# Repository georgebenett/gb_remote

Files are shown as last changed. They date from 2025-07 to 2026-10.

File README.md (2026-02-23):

# GB Remote

<div align="center">
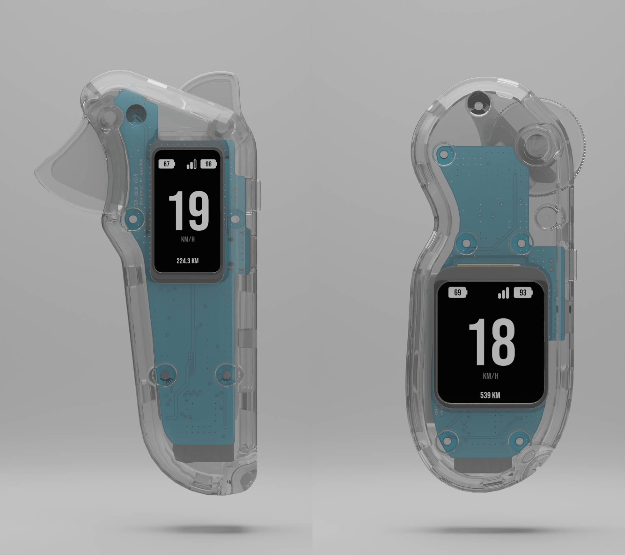
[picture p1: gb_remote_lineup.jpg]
GB Controller
  
</div>

A firmware open-source hand controller for electric skateboards built with the ESP32S3. This project provides a complete wireless control solution with real-time telemetry monitoring, featuring a custom BLE protocol that communicates with VESC motor controllers and Jiabaida/Kaly BMS systems.

This repository contains the **remote controller firmware**. The complete system also includes:
- **Receiver Firmware** (`gb_receiver`): The BLE server firmware that runs on the receiver

## Key Features

### Intuitive Control Interface
- **Analog Throttle Control**: High-precision ADC-based throttle input with automatic calibration
- **Dual Throttle Support**: Separate throttle and brake inputs on dual throttle variant with neutral position
- **Smart Button Interface**: Multi-function button with long-press and double-press detection
- **Haptic Feedback**: Vibration patterns for connection status, alerts, and user feedback
- **Sleep Management**: Automatic power management with inactivity detection and power modes
- **Power Management**: Soft latching hardware where power consumption while "sleeping is 1uA"

### Modern UI
- **LVGL Graphics Library**: Beautiful, responsive user interface built with EEZ Studio (open-source)
- **Real-time Speed Display**: Large, easy-to-read speedometer with km/h and mi/h display
- **Dual Battery Monitoring**: Separate battery indicators for controller and skateboard
- **Connection Status**: Visual feedback for BLE connection quality
- **Trip Distance Tracking**: Built-in odometer with persistent storage
- **Adjustable Backlight**: Configurable display brightness (1-100%)

### Comprehensive Telemetry
- **VESC Integration**: Real-time data from VESC
- **BMS Support**: Full battery management system monitoring with cell-level voltage tracking
  - **Compatible BMS Systems**: Jiabaida and Kaly BMS telemetry support
  - **Cell Voltage Monitoring**: Individual cell voltage tracking for up to 16 cells
  - **Capacity Tracking**: Real-time remaining and nominal capacity monitoring
- **Custom BLE Protocol**: Optimized data transmission for low latency and high reliability
- **Automatic Parameter Configuration**: Motor pulley, wheel diameter, and throttle settings are automatically retrieved by the receiver from the vesc

## Hardware Variants

The firmware supports two hardware variants:

### GB Remote Lite
- **Display**: 240×320 pixel TFT LCD
- **Throttle**: Single analog throttle with inversion support
- **Use Case**: Standard single-throttle control

### GB Remote Dual Throttle
- **Display**: 172×320 pixel TFT LCD
- **Throttle**: Dual analog inputs (throttle + brake)
- **Use Case**: Separate throttle and brake control with neutral position

Both variants share the same core firmware with target-specific configurations.

## Technical Specifications

### Hardware Platform
- **MCU**: ESP32 S3
- **Display**: TFT LCD ST7789 (resolution varies by variant)
- **Input**: Analog throttle with ADC calibration (dual inputs on dual throttle variant)
- **Connectivity**: Bluetooth Low Energy (BLE) SPP client
- **Power**: Built-in battery monitoring and power management
- **Haptic Feedback**: Vibration motor for user notifications

### Software Architecture
- **RTOS**: FreeRTOS for real-time task management
- **Graphics**: LVGL 8.3.6 with EEZ Studio UI
- **Communication**: Custom BLE SPP protocol for VESC/BMS data
- **Storage**: NVS flash for configuration and trip data
- **Power Management**: Advanced power modes and soft latching circuit

## Communication Protocol

### BLE SPP Protocol
- **Service UUID**: `0xABF0`
- **Data Characteristic**: `0xABF2`
- **Protocol**: Custom BLE SPP for low-latency communication with receiver
- **Data Exchange**: Throttle/brake commands from remote, VESC and BMS telemetry from receiver

### USB Serial Binary Protocol
The remote communicates with the configuration tool via a binary protocol over USB Serial (USB CDC):

- **Packet-based**: Binary protocol with CRC-16-CCITT error checking
- **Real-time Streaming**: Configurable data streaming (1-100 Hz) for monitoring and debugging
- **Commands**: Firmware version, configuration management, calibration, odometer control, BLE trim adjustment
- **Documentation**: See [`firmware/docs/USB_SERIAL_PROTOCOL.md`](firmware/docs/USB_SERIAL_PROTOCOL.md) for complete protocol specification

## Project Structure

This repository contains the **remote controller firmware**. The complete GB Remote system consists of:

1. **Remote Controller** (this repository): ESP32S3-based hand controller with display and throttle
2. **Receiver Firmware** (`gb_receiver`): BLE server firmware for the skateboard/receiver side that interfaces with VESC and BMS

## Getting Started

### Prerequisites
- ESP-IDF development environment

### Build & Flash

The project includes build scripts for easy compilation:

- **Lite variant**: `./lite_build.sh` - Builds for 240×320 display with single throttle
- **Dual Throttle variant**: `./dual_throttle_build.sh` - Builds for 172×320 display with dual throttle/brake
- **Release build**: `./build_and_release.sh` - Builds both variants for release

After building, flash using ESP-IDF:
```bash
idf.py flash monitor
```

Or use the [Configuration Tool](https://gbengineering.se/config-tool/) for easy firmware updates.

## Configuration Tool

**Easy Configuration via Web Interface**

Configure your GB Remote controller easily using our online configuration tool hosted on the GB Engineering website:

**[GB Remote Configuration Tool](https://gbengineering.se/config-tool/)**

The configuration tool provides a comprehensive web-based interface for setting up and managing your GB Remote system.

### Features:
- **USB Serial Connection**: Connect directly via USB cable
- **Real-time Configuration**: Adjust settings without recompiling firmware
- **Automatic Firmware Updates**: The configuration tool automatically checks for firmware updates every time the remote is connected. Update with a simple button confirmation
- **Throttle Calibration**: Calibrate throttle and brake inputs with guided calibration process
- **Speed Unit Toggle**: Switch between km/h and mph display units
- **Backlight Control**: Adjustable display brightness (0-100%)
- **BLE Trim Adjustment**: Fine-tune BLE output offset for precise throttle control
- **Odometer Management**: Reset trip distance counter
- **Real-time Data Streaming**: Monitor live telemetry data at configurable rates (1-100 Hz)
- **Status Monitoring**: Real-time device status and logs

### Quick Setup:
1. Flash the firmware to your Remote (and Receiver if needed)
2. Connect your controller via USB cable
3. Open the [Configuration Tool](https://gbengineering.se/config-tool/)
4. Click "Connect to Remote" to establish USB serial connection
5. Configure your settings and calibrate throttle

## BMS Compatibility

This controller is specifically designed to work with popular electric skateboard BMS systems:

- **Jaiabaida BMS**: Full telemetry support including cell voltages and capacity data
- **Kaly BMS**: Complete compatibility with all monitoring features

The receiver firmware (`gb_receiver`) handles the BMS communication and forwards the telemetry data to the remote controller via BLE.

## Contributing

This project is open source and welcomes contributions! Whether you're fixing bugs, adding features, or improving documentation, your help is appreciated.

### Pre-commit hooks

To enable auto-formatting (trailing whitespace trim + clang-format on C/C++ files) before each commit:

```bash
git config core.hooksPath githooks
```

Requires [clang-format](https://clang.llvm.org/docs/ClangFormat.html) (e.g. `brew install clang-format` on macOS).

## License

**Creative Commons Attribution-NonCommercial 4.0 International (CC BY-NC 4.0)**

This work is licensed under the Creative Commons Attribution-NonCommercial 4.0 International License. To view a copy of this license, visit [http://creativecommons.org/licenses/by-nc-nd/4.0/](http://creativecommons.org/licenses/by-nc-nd/4.0/).

### What this means:

**You are free to:**
- Share - copy and redistribute the material in any medium or format
- Adapt - remix, transform, and build upon the material
- Use for personal, educational, and research purposes

**You may NOT:**
- Use for commercial purposes (selling, commercial distribution, etc.)
- Create derivative works (modify and redistribute)
- Use without proper attribution to the original author

### Commercial Use:
For commercial use, licensing, or commercial distribution of this project, please contact the author for licensing terms and fees.

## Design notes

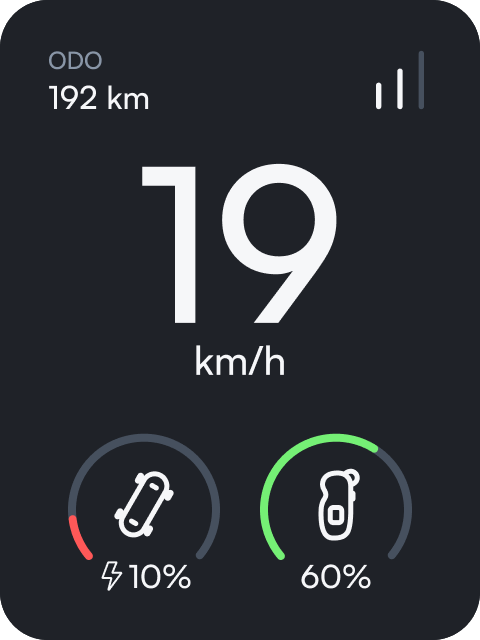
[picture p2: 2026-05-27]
UI/eez_dual_throttle/assets/reference.png

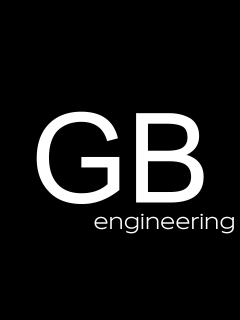
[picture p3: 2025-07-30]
UI/eez_dual_throttle/assets/GB.png

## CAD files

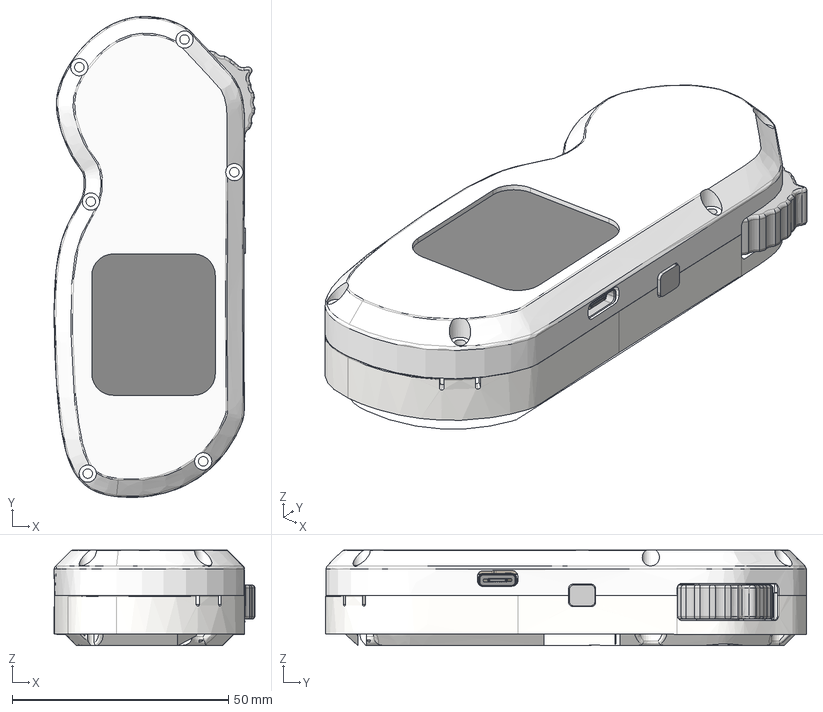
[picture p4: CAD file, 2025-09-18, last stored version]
mechanics/vesc hand controller prot 2 v31.step
46.5 x 111.3 x 24.0 mm
front cover
back cover
PCB (1)
Display (1)
R-0603 (1) x 3
C-0603 (1) x 2
U-0603 (1)
display cover
BOSS-EXTRUDE14_8_
BOSS-EXTRUDE7_4_
BOSS-EXTRUDE7_3_
BOSS-EXTRUDE14_4_
BOSS-EXTRUDE14_2_
BOSS-EXTRUDE14_11_
BOSS-EXTRUDE7_7_
BOSS-EXTRUDE14_9_
BOSS-EXTRUDE14_3_
BOSS-EXTRUDE14_7_
MIRROR2
BOSS-EXTRUDE14_5_
BOSS-EXTRUDE14_12_
BOSS-EXTRUDE7_8_
BOSS-EXTRUDE7_1_
BOSS-EXTRUDE14_10_
BOSS-EXTRUDE7_9_
BOSS-EXTRUDE14_6_
BOSS-EXTRUDE14_1_
BOSS-EXTRUDE7_6_
BOSS-EXTRUDE7_2_
CUT-EXTRUDE5
BOSS-EXTRUDE7_5_
U.FL Connector v1
Button (1) x 2
Shield
retreat v1
7487N25_Precision Stainless Steel Ball Bearing (1) x 2
new throttle
power switch
power button

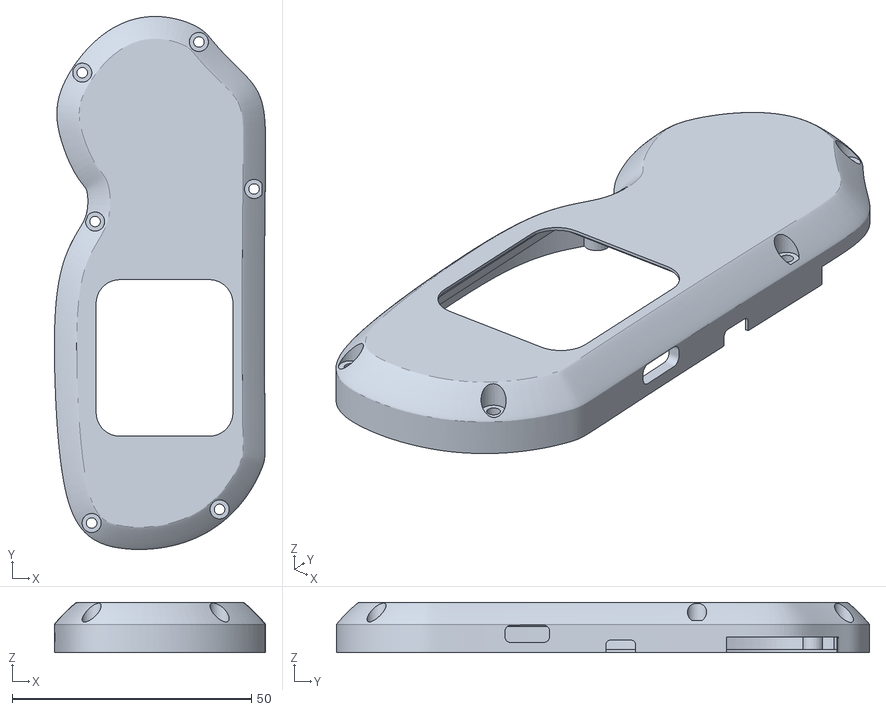
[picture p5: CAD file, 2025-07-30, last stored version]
mechanics/front.stl
44.1 x 111.3 x 10.5

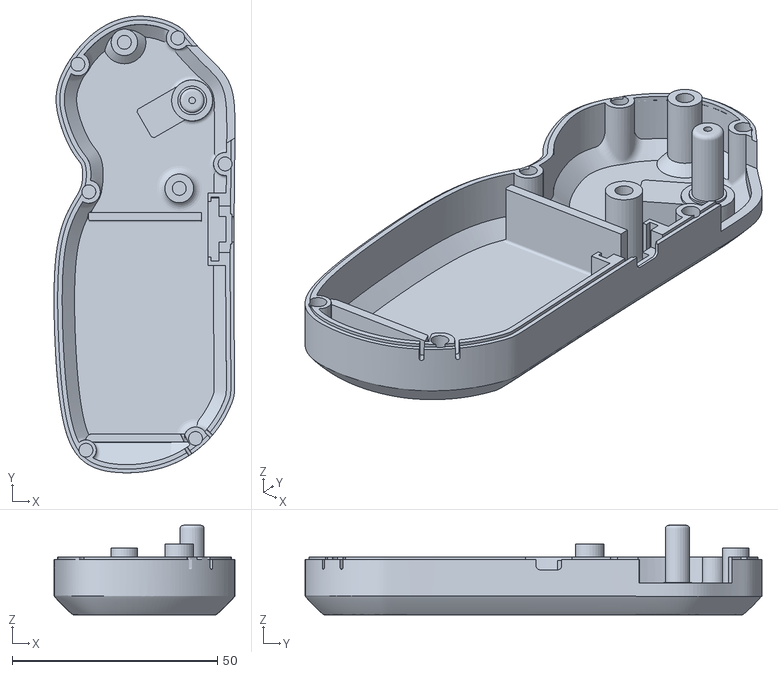
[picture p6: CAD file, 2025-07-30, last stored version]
mechanics/back.stl
44.1 x 111.3 x 21.8

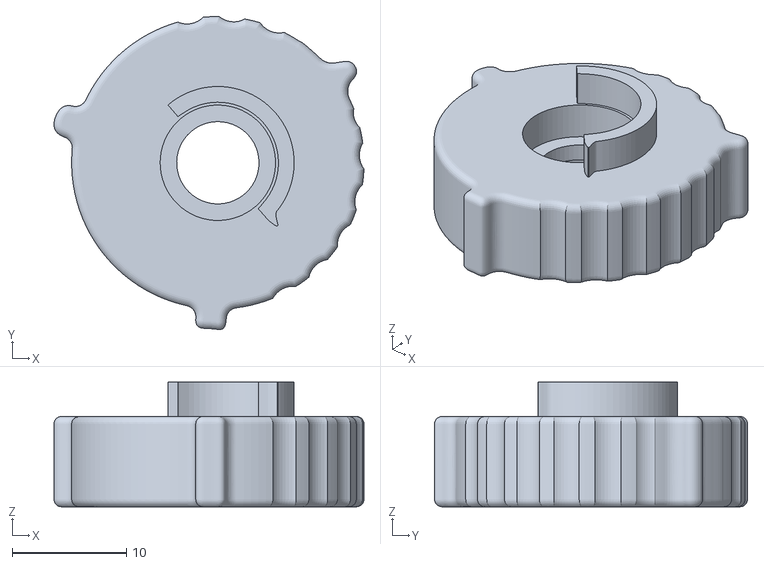
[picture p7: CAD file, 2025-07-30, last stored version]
mechanics/throttle.stl
27.1 x 27.4 x 10.9

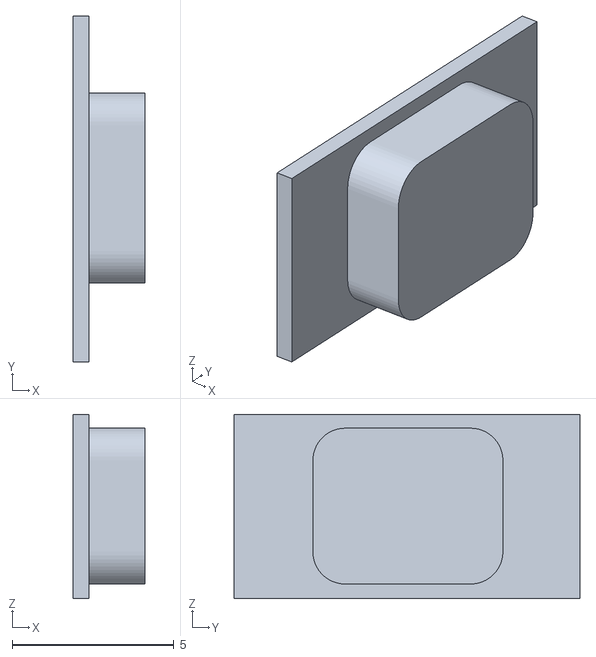
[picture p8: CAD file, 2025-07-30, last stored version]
mechanics/power_button.stl
2.23 x 10.7 x 5.70

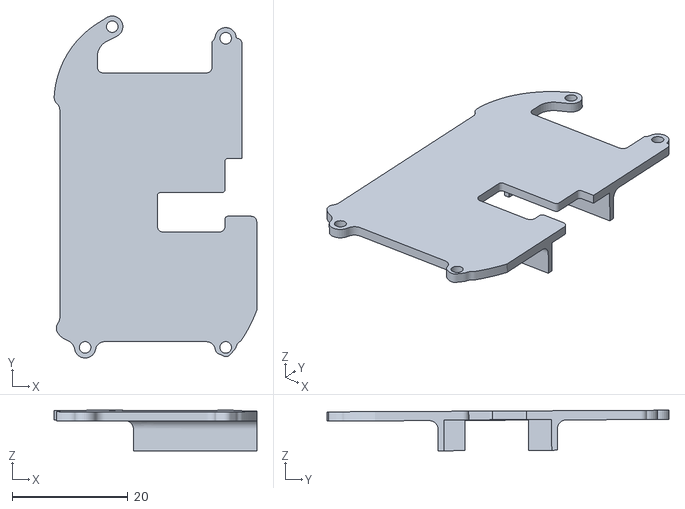
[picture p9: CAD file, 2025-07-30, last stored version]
mechanics/display_cover.stl
35.0 x 59.1 x 7.02

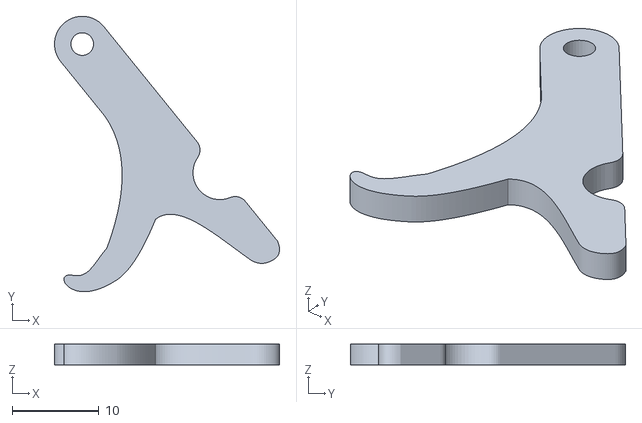
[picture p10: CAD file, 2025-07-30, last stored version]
mechanics/retreat.stl
25.9 x 31.7 x 2.40

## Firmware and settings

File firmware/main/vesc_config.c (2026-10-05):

#include "vesc_config.h"
#include "ble.h"
#include "esp_log.h"
#include "nvs.h"
#include "nvs_flash.h"
#include <math.h>

#define TAG "VESC_CONFIG"

// Current motor config from VESC (volatile, updated via BLE)
static vesc_motor_config_t current_motor_config = {
    .motor_poles = 10,        // Default until VESC sends config
    .gear_ratio_x1000 = 1000, // Default until VESC sends config
    .wheel_diameter_mm = 100, // Default until VESC sends config
};

// Default user preferences (saved to NVS)
static const vesc_config_t default_config = {
    .motor_poles = 11,        // Will be overwritten by VESC
    .gear_ratio_x1000 = 1001, // Will be overwritten by VESC
    .wheel_diameter_mm = 101, // Will be overwritten by VESC
    .speed_unit_mph = false,  // Speed unit: km/h by default
    .dual_connection = false, // Single receiver connection by default
    .battery_cells = 0,     // Unset: show pack voltage until user sets S count
    .battery_cell_type = 0, // High-drain li-ion (P42A/30Q/40T class)
    .smart_reverse = false,
    .no_reverse = false,
    .throttle_curve_acc = 0,
    .throttle_curve_brake = 0,
    .throttle_curve_mode = THROTTLE_CURVE_EXPO,
    .assist_push = false,
    .assist_strength = ASSIST_STRENGTH_DEFAULT,
    .assist_decay = ASSIST_DECAY_DEFAULT,
    .speed_limit_mode = 0,
    .ride_profile = RIDE_PROFILE_ROCKET,
#ifdef CONFIG_TARGET_LITE
    .invert_throttle = false // Throttle inversion disabled by default
#endif
};

esp_err_t vesc_config_init(void) {
  // Try to load user preferences, if it fails (first time) save defaults
  vesc_config_t config;
  esp_err_t err = vesc_config_load(&config);

  if (err == ESP_ERR_NVS_NOT_FOUND) {
    ESP_LOGI(TAG, "No user preferences found, saving defaults");
    return vesc_config_save(&default_config);
  }

  return err;
}

esp_err_t vesc_config_load(vesc_config_t *config) {
  nvs_handle_t nvs_handle;
  esp_err_t err;

  // Start with current motor config from VESC (or defaults if not yet received)
  config->motor_poles = current_motor_config.motor_poles;
  config->gear_ratio_x1000 = current_motor_config.gear_ratio_x1000;
  config->wheel_diameter_mm = current_motor_config.wheel_diameter_mm;

  config->speed_unit_mph = false;
  config->dual_connection = false;
  config->battery_cells = 0;
  config->battery_cell_type = 0;
  config->smart_reverse = false;
  config->no_reverse = false;
  config->throttle_curve_acc = 0;
  config->throttle_curve_brake = 0;
  config->throttle_curve_mode = THROTTLE_CURVE_EXPO;
  config->assist_push = false;
  config->assist_strength = ASSIST_STRENGTH_DEFAULT;
  config->assist_decay = ASSIST_DECAY_DEFAULT;
  config->speed_limit_mode = 0;
  config->ride_profile = RIDE_PROFILE_ROCKET;
#ifdef CONFIG_TARGET_LITE
  config->invert_throttle = false;
#endif

  err = nvs_open(VESC_NVS_NAMESPACE, NVS_READONLY, &nvs_handle);
  if (err != ESP_OK) {
    // No NVS data, use defaults - this is OK
    return (err == ESP_ERR_NVS_NOT_FOUND) ? ESP_OK : err;
  }

  uint8_t speed_unit;
  err = nvs_get_u8(nvs_handle, NVS_KEY_SPEED_UNIT, &speed_unit);
  if (err == ESP_OK) {
    config->speed_unit_mph = (bool)speed_unit;
  }

  uint8_t dual_connection;
  err = nvs_get_u8(nvs_handle, NVS_KEY_DUAL_CONNECTION, &dual_connection);
  if (err == ESP_OK) {
    config->dual_connection = (bool)dual_connection;
  }

  uint8_t battery_cells;
  err = nvs_get_u8(nvs_handle, NVS_KEY_BATTERY_CELLS, &battery_cells);
  if (err == ESP_OK) {
    config->battery_cells = battery_cells;
  }

  uint8_t battery_cell_type;
  err = nvs_get_u8(nvs_handle, NVS_KEY_BATTERY_CELL_TYPE, &battery_cell_type);
  if (err == ESP_OK) {
    config->battery_cell_type = battery_cell_type;
  }

  uint8_t smart_reverse;
  err = nvs_get_u8(nvs_handle, NVS_KEY_SMART_REVERSE, &smart_reverse);
  if (err == ESP_OK) {
    config->smart_reverse = (bool)smart_reverse;
  }

  uint8_t no_reverse;
  err = nvs_get_u8(nvs_handle, NVS_KEY_NO_REVERSE, &no_reverse);
  if (err == ESP_OK) {
    config->no_reverse = (bool)no_reverse;
  }

  /* Out-of-range curve values are dropped, not clamped: a bad read gives the
   * rider linear, not a shape they never asked for. */
  int8_t curve_acc;
  err = nvs_get_i8(nvs_handle, NVS_KEY_CURVE_ACC, &curve_acc);
  if (err == ESP_OK && curve_acc >= THROTTLE_CURVE_MIN &&
      curve_acc <= THROTTLE_CURVE_MAX) {
    config->throttle_curve_acc = curve_acc;
  }

  int8_t curve_brake;
  err = nvs_get_i8(nvs_handle, NVS_KEY_CURVE_BRAKE, &curve_brake);
  if (err == ESP_OK && curve_brake >= THROTTLE_CURVE_MIN &&
      curve_brake <= THROTTLE_CURVE_MAX) {
    config->throttle_curve_brake = curve_brake;
  }

  uint8_t curve_mode;
  err = nvs_get_u8(nvs_handle, NVS_KEY_CURVE_MODE, &curve_mode);
  if (err == ESP_OK && curve_mode < THROTTLE_CURVE_MODE_COUNT) {
    config->throttle_curve_mode = curve_mode;
  }

  uint8_t assist_push;
  err = nvs_get_u8(nvs_handle, NVS_KEY_ASSIST_PUSH, &assist_push);
  if (err == ESP_OK) {
    config->assist_push = (bool)assist_push;
  }
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

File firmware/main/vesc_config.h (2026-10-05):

#ifndef VESC_CONFIG_H
#define VESC_CONFIG_H

#include "esp_err.h"
#include "sdkconfig.h"
#include "throttle_math.h"
#include <stdbool.h>
#include <stdint.h>

// NVS Storage keys (only user preferences are persisted)
#define VESC_NVS_NAMESPACE "vesc_cfg"
#define NVS_KEY_SPEED_UNIT "speed_unit"
#define NVS_KEY_DUAL_CONNECTION "dual_conn"
#define NVS_KEY_BATTERY_CELLS "batt_cells"
#define NVS_KEY_BATTERY_CELL_TYPE "batt_celltyp"
#define NVS_KEY_SMART_REVERSE "smart_rev"
#define NVS_KEY_ASSIST_PUSH "assist_push"
#define NVS_KEY_ASSIST_STRENGTH "assist_str"
#define NVS_KEY_ASSIST_DECAY "assist_dec"
#define NVS_KEY_NO_REVERSE "no_reverse"
#define NVS_KEY_CURVE_ACC "curve_acc"
#define NVS_KEY_CURVE_BRAKE "curve_brk"
#define NVS_KEY_CURVE_MODE "curve_mode"
#define NVS_KEY_SPEED_LIMIT "speed_limit"
#define NVS_KEY_RIDE_PROFILE "ride_profile"

// Speed limit modes: Off, 20 km/h, 25 km/h, 20 mph, 25 mph.
#define SPEED_LIMIT_MODE_COUNT 5

// Ride profiles: Beginner, Eco, Medium, Rocket.
#define RIDE_PROFILE_COUNT 4
#define RIDE_PROFILE_ROCKET (RIDE_PROFILE_COUNT - 1) // instant, no cap

// Assistive push tuning, clamped again by the receiver that runs it.
#define ASSIST_STRENGTH_DEFAULT 15 // percent of the VESC current limit
#define ASSIST_STRENGTH_MIN 5
#define ASSIST_STRENGTH_MAX 50
#define ASSIST_DECAY_DEFAULT 30 // motor rpm/s bled off the held speed
#define ASSIST_DECAY_MIN 10
#define ASSIST_DECAY_MAX 120
#ifdef CONFIG_TARGET_LITE
#define NVS_KEY_INVERT_THROTTLE "inv_throttle"
#endif

// Motor configuration from VESC (received via BLE, NOT persisted)
typedef struct {
  uint8_t motor_poles;        // Number of motor poles (from VESC via BLE)
  uint16_t gear_ratio_x1000;  // Gear ratio * 1000 (from VESC via BLE)
  uint16_t wheel_diameter_mm; // Wheel diameter in mm (from VESC via BLE)
} vesc_motor_config_t;

// Full config including user preferences
typedef struct {
  // Motor config from VESC (volatile - not saved to NVS)
  uint8_t motor_poles;        // Number of motor poles (from VESC via BLE)
  uint16_t gear_ratio_x1000;  // Gear ratio * 1000 (from VESC via BLE)
  uint16_t wheel_diameter_mm; // Wheel diameter in mm (from VESC via BLE)
  // User preferences (persisted to NVS)
  bool speed_unit_mph;       // Speed unit: false = km/h, true = mph
  bool dual_connection;      // Allow connecting to two receivers simultaneously
  uint8_t battery_cells;     // Skate pack series count: 0 = unset (show pack
                             // voltage), else 5..20 (estimate percentage)
  uint8_t battery_cell_type; // Cell chemistry (battery_cell_type_t) picking
                             // which SoC curve the estimate uses
  bool smart_reverse;        // VESC-style smart reverse, run by the receiver
  bool no_reverse;           // Below neutral only brakes, run by the receiver
  int8_t throttle_curve_acc; // Throttle curve, tenths (see throttle_math.h)
  int8_t throttle_curve_brake; // Brake curve, tenths
  uint8_t throttle_curve_mode; // throttle_curve_mode_t
  bool assist_push;        // Assistive push (endless mode), run by the receiver
  uint8_t assist_strength; // Assistive push strength, percent of current limit
  uint8_t assist_decay;    // Assistive push decay, motor rpm/s
  uint8_t speed_limit_mode; // 0 off, 1 20km/h, 2 25km/h, 3 20mph, 4 25mph;
                            // enforced by the receiver
  uint8_t ride_profile;     // 0 Beginner .. 3 Rocket: eased throttle ramp here,
                            // drive current cap on the receiver. Rocket = off.
#ifdef CONFIG_TARGET_LITE
  bool invert_throttle; // Whether to invert throttle direction
#endif
} vesc_config_t;

esp_err_t vesc_config_init(void);
esp_err_t vesc_config_load(vesc_config_t *config);
esp_err_t
vesc_config_save(const vesc_config_t *config); // Only saves user preferences
int32_t vesc_config_get_speed(const vesc_config_t *config);

// The cap a speed_limit_mode enforces, in km/h; 0 means no limit.
float vesc_config_speed_limit_kmh(uint8_t speed_limit_mode);

// Time (ms) a profile takes to ramp neutral -> full throttle; 0 = instant.
// Braking is never ramped.
uint16_t vesc_config_ride_profile_ramp_ms(uint8_t ride_profile);

// Percent of max motor current the profile may drive; enforced by the receiver.
uint8_t vesc_config_ride_profile_current_pct(uint8_t ride_profile);

// Update motor config from VESC (called by BLE when data is received)
void vesc_config_update_motor(uint8_t motor_poles, uint16_t gear_ratio_x1000,
                              uint16_t wheel_diameter_mm);

#endif // VESC_CONFIG_H

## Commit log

2025-07-30 adding mech
    [back.stl, display_cover.stl, front.stl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]
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2025-08-26 fixing partition size to fit coredump on flash
    [partitions.csv]
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2025-09-18 adding remote step file
    [vesc hand controller prot 2 v31.step]
2025-09-19 fixing mi/h and km/h text on UI at boot
    [vesc_config.c]
2025-09-19 fixing battery level calibration
    [battery.c, battery.h]
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2025-10-16 porting to EEZ Studio
    [partitions.csv]
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2025-10-31 fixing adc wrongly naming, replace with throttle name instead
    [battery.c, battery.h, lcd.c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]
2025-10-31 fix generic function naming from adc to throttle
    [throttle.c, throttle.h]
2025-11-01 inverting screen 180 degrees
    [lcd.c]
2025-11-01 removing invert throttle
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2025-11-02 adding power module, adding vesc voltage display if bms is not connected
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2025-11-02 fix stack overflow on button task
    [button.c]
2025-11-03 fixing backlight levels and flash script
    [lcd.c, lcd.h, power.c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]
2025-11-03 ui_updater: fix unused function
    [ui_updater.c, ui_updater.h]
2025-11-04 fix buildtree
    [back.stl, display_cover.stl, front.stl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]
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2025-11-11 fix timing on the ui tasks to have more stability
    [lcd.c, throttle.c, ui_updater.c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]
2025-11-12 fix ui functions not taking mutex first
    [ui_updater.c]
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2025-11-12 rework on power module
    [ble.c, button.c, power.c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]
2025-11-18 viber: higher short pulsing time
    [viber.c]
2025-12-01 fix dual throttle calibration handling
2025-12-01 ui_updater: write to nvs when reset odometer
    [ui_updater.c]
2025-12-01 fix invert throttle
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2025-12-11 replace direct mutex calls with command queue for all LVGL updates
    [power.c, ui_updater.c]
2025-12-11 fix calibration bug on dual throttle
    [ble.c, throttle.c, throttle.h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]
2025-12-11 rework on serial handler, motor config aquired from server at runtime
    [ble.c, vesc_config.c, vesc_config.h]
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2025-12-13 dual throttle raw adc inverted logic
    [throttle.c]
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2025-12-14 fix battery init in throttle
    [battery.c, battery.h, throttle.c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]
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2025-12-17 ble: fix type-limits warning
    [ble.c]
2025-12-17 Add wake-up from sleep with long press on main button
    - Configure button GPIO as wake-up source before entering deep sleep
    - Add power_check_wake_from_sleep() to detect wake and verify long press
    - Require 500ms long press to turn device on after sleep
    - Add power_sleep_immediate() for quick sleep when wake-up check fails
    - Check wake-up status early in app_main() before full initialization
    [power.c]
2026-01-06 Fix: Invert trim offset when throttle is inverted
    When throttle inversion is enabled, the trim offset direction must also be inverted to maintain correct compensation. This ensures that trim adjustments work correctly regardless of throttle inversion state.
    [ble.c]
2026-01-09 Optimize task timings and add LVGL mutex protection
    - Reduce task frequencies to improve system stability:
    * ADC task: 20ms -> 30ms (50Hz -> 33Hz)
    * LVGL handler: 10ms -> 16ms (100Hz -> 62.5Hz)
    * USB serial: 10ms -> 20ms (100Hz -> 50Hz)
    * Button monitor: 10ms -> 20ms (100Hz -> 50Hz)
    * Speed update: 20ms -> 50ms (50Hz -> 20Hz)
    * BLE ADC send: 50ms -> 75ms (20Hz -> ~13Hz)
    - Add mutex protection for all LVGL screen switching operations:
    * power.c: Screen switching now thread-safe
    * button.c: Screen switching now thread-safe
    * Fixes race condition causing delayed home screen return
    - Fix variable scope in usb_serial.c (throttle_inverted)
    - Bump version to 1.2.0
    [ble.c, button.c, lcd.c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]
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2026-01-23 Add BLE pairing and paired device persistence (v2.0.0)
    - Add NVS storage for paired server MAC address
    - Implement BLE security with passkey authentication (MITM protection)
    - Prioritize reconnecting to last paired device on startup/disconnect
    - Fall back to scanning for any device after 15 second timeout
    - Fix scan race condition by waiting for stop complete event before restarting
    - Remove unnecessary watchdog from connection update task
    [ble.c, ble.h, ui_updater.c]
2026-01-26 fix button handling to interrupt based instead of polling
    [button.c]
2026-02-03 fix button_monitor task watchdog timeout and reduce BLE reconnect timeout
    - Fix watchdog trigger by replacing portMAX_DELAY with 4s timeout in button task
    - Add watchdog reset in startup button-release wait loop
    - Reduce BLE paired device reconnect timeout from 15s to 5s
    [ble.c, button.c]
2026-02-05 refactor: clean up main.c structure and improve modularity
    - Move backlight loading/fading to lcd.c (lcd_load_saved_brightness, lcd_fade_to_saved_brightness)
    - Move splash screen logic to ui_updater.c (ui_show_splash_screen)
    - Encapsulate power wake check inside power_init() - no longer exposed in header
    - Use ble_is_connected() instead of extern is_connect
    - Make error handling consistent: ESP_ERROR_CHECK for critical only (button, adc, battery)
    - Non-critical failures (viber, vesc_config) now log warnings and continue
    - Remove duplicate ui_update_aux_output_indicator call
    - main.c reduced from 166 to 119 lines, now pure orchestration
    [lcd.c, lcd.h, power.c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]
2026-02-05 fix: resolve task watchdog timeouts in UI update tasks
    - Move watchdog reset to start of loop in all UI tasks
    - Split connection_update_task's 5s delay into 1s chunks
    - Ensures watchdog is reset before any potentially blocking operations
    The conn_update task was triggering watchdog because it slept for
    5 seconds (CONNECTION_UPDATE_MS) which equals the watchdog timeout.
    [ui_updater.c]
2026-02-05 refactor: improve code quality and industry standards compliance
    - Add named constants for magic number delays across all modules
    - Fix BREAK_PIN typo to BRAKE_PIN in hw_config.h and throttle.c
    - Replace extern variable with getter function (power_is_entering_off_mode)
    - Replace assert() with proper error handling in lcd.c buffer allocation
    - Remove dead code (unreachable vTaskDelete in ble.c)
    - Add comprehensive error handling documentation in main.c
    - Use volatile for shared state visibility across tasks
    - Remove watchdog from non-critical connection_update_task
    [battery.c, ble.c, lcd.c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]
2026-02-05 fix: improve BLE thread safety and ADC reliability
    - Replace direct is_connect access with thread-safe ble_is_connected()
    - Make is_connect static and remove extern declaration from header
    - Fix memory leak in MTU reconfig by freeing db before reallocation
    - Fix incorrect reconnect timeout log message (was hardcoded)
    - Improve throttle/brake ADC validation with min sample requirement
    - Add stuck-value detection for throttle/brake sensors
    - Add outlier rejection to battery ADC using trimmed mean
    [battery.c, ble.c, ble.h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]
2026-02-05 fix: critical safety and reliability improvements
    CRITICAL SAFETY FIXES:
    - Fix LITE mode ADC error handling: errors now map to neutral (128), not throttle (0)
    - Block throttle transmission when battery is critically low
    - Add division-by-zero protection in map_throttle_value() and map_brake_value()
    THREAD SAFETY FIXES:
    - Replace all direct is_connect access with ble_is_connected() for mutex protection
    - throttle.c, power.c, ui_updater.c, usb_serial.c, ble.c (adc_send_task)
    RELIABILITY IMPROVEMENTS:
    - Add neutral dead zone (±3 units) to prevent unintended motion from ADC noise
    - Add watchdog registration to connection_update_task
    - Validate calibration values on NVS load (range, min<max,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
    [ble.c, power.c, throttle.c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]
2026-02-15 swapped mi/h to mph
    [ui_updater.c, vesc_config.h]
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2026-03-01 fix race in adc_send_task
    [ble.c]
2026-03-01 fix ble watchdog bug
    [ble.c]
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2026-03-03 fix ble throttle issue!
    [ble.c, ble.h, power.c]
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2026-03-06 fix throttle center point in lite
    [throttle.c]
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2026-04-01 remove receiver-side reconnect preference logic
    Reconnect intelligence has moved to the receiver. Remote no longer saves
    or filters by receiver MAC — it simply scans for any GS-THUMB device on
    boot and after disconnect. Removes paired server NVS storage, reconnect
    timer, and reconnect handler task.
    [ble.c, ble.h]
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2026-04-09 fix adc calibration lock when empty flash
    [throttle.c]
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2026-04-23 fix lite power state ui icon location
2026-04-24 add throttle calibration error to UI
    [ui_updater.c, ui_updater.h]
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2026-04-25 Fix shutdown completion feedback and timing
    [power.c]
2026-04-26 add reset odometer function to remote: odometer is saved into receiver nvs, remote sends a command to resets its odometer
    [ble.c, ble.h]
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2026-04-27 use per-target build dirs and sdkconfig files to avoid mutating shared config on target switch
2026-05-06 add mutex to adc_oneshot to avoid race conditions
    [battery.c, throttle.c, throttle.h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]
2026-05-06 fix vesc voltage not showing when bms disconnected
    [ble.c, ui_updater.c]
2026-05-07 fix a few bugs on snake game
    [throttle.c]
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2026-05-13 harden build_and_release.sh against wrong-chip releases
    force idf.py set-target from sdkconfig.defaults.<target> at the start of
    each build, and assert bootloader byte 12 matches the expected chip id
    before packaging. v2.1.15 shipped a c3 bootloader because a stale
    sdkconfig overrode the s3 defaults; this catches that at release time
    instead of on the device side.
2026-05-13 advertise GS-REM while not connected for pairing discovery, v2.2.0
    The receiver scans for nearby remotes by their advertised name during
    the pair flow. Add non-connectable advertising (ADV_TYPE_NONCONN_IND)
    that runs whenever the remote is idle (not connected, not suspended)
    and is stopped on connect/suspend. GATT-client behavior is unchanged.
2026-05-16 reduce BLE throttle latency for racing
    - ADC_SEND_INTERVAL_MS 75 → 20 ms (50 Hz send rate)
    - ADC_SAMPLING_TICKS 30 → 15 ms (fresher cached value)
    - Request 20 ms BLE connection interval on connect so the stack
    delivers packets at the rate we send them
    - Dual throttle: use cached adc_get_latest_value() in send path instead
    of calling get_throttle_brake_ble_value() which did 10 fresh ADC reads
    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
2026-05-20 add neutral deadband macro, neutral window was too tight on remotes
    [ble.c, vesc_config.h]
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2026-05-28 add missing dual throttle files
2026-07-29 throttle: dedupe ADC reads and centralize trim mapping
    - Fold throttle_read_value/brake_read_value into one adc_read_avg helper;
    they were byte-identical apart from the channel and log string.
    - Add throttle_apply_trim(), the single implementation of the trim/neutral
    mapping that ble.c and usb_serial.c each had their own copy of.
    - Make map_throttle_value static and lite-only, dropping the map_adc_value
    wrapper that only forwarded to it.
    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
2026-07-29 battery: drop unused and duplicated constants
    BATTERY_MAX_VOLTAGE was never read, and ADC_SAMPLE_MS is already defined in
    throttle.h, which battery.c includes.
2026-07-29 ble: drop the single-profile dispatch table and unused telemetry state
    - Remove gl_profile_tab / gattc_profile_inst: with PROFILE_NUM == 1 the
    lookup loop always resolved to the one handler, so esp_gattc_cb now calls
    gattc_profile_event_handler directly and keeps the interface in
    spp_gattc_if (typed esp_gatt_if_t, ESP_GATT_IF_NONE until registered).
    - Delete spp_uart_init/uart_task and spp_uart_queue: nothing ever fed
    UART0 data to the receivers, and the driver install held 12 KB.
    - Stop caching temperatures, currents, cell voltages and cell count that
    no screen reads; they are decoded locally for the log line only.
    - Use throttle_apply_trim() instead of an inline copy of the trim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
    [ble.c, ble.h]
2026-07-29 ui_updater: remove dead API and share the splash label setup
    - Drop ui_create_aux_output_indicator(), a NULL check plus a call to
    ui_update_aux_output_indicator(); app_init now calls the latter directly.
    - Delete ui_update_connection_quality()/get_connection_quality() and the
    connection_quality state: ble.c calls ui_update_connection_icon() itself.
    - Delete ui_check_mutex_health() (never called; swapping a live mutex
    under waiters was unsound anyway) and take_lvgl_mutex_for_handler().
    - Factor the firmware version + MAC label fill into splash_set_labels(),
    duplicated between ui_show_splash_then_home and ui_show_splash_screen.
    - Drop the never-implemented motor/battery current and con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
    [ui_updater.c, ui_updater.h]
2026-07-29 button: remove unused state tracking and screen callback
    - Drop button_state_t and current_state: nothing read them, the events
    already carry the transition.
    - Delete button_get_state, button_get_press_duration_ms,
    button_unregister_callback, the no-op default handler and
    switch_to_screen2_callback (shutdown screen is driven from power.c).
    - Remove the second button_start_monitoring() call in app_init; it is
    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
2026-07-29 usb_serial: add LE payload writers and one charging-mode gate
    - Add put_u16/put_u32 helpers and use them for every little-endian field;
    the manual four-line shift-and-mask blocks appeared 20+ times.
    - Reject commands that need the full app once in
    usb_serial_process_packet() via cmd_needs_full_mode(), instead of the
    same POWER_MODE_CHARGING check repeated in nine handlers.
    - Use throttle_apply_trim() instead of the local copy of the trim mapping.
    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
2026-07-29 vesc_config: drop unused vesc_config_get_motor
    Nothing read the motor config back out; the values are consumed straight
    from vesc_config_t.
2026-07-29 viber: replace the pattern switch with a lookup table
    The seven-case switch only picked an array and its length. A table indexed
    by viber_pattern_t does the same with a bounds check.
    Also drop viber_vibrate, viber_custom_pattern, viber_stop and the shutdown
    song: no caller, and shutdown already has its own haptic feedback.
    [viber.c, viber.h]
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2026-08-30 add shutdown command to avoid failsafe when turning off the remote manually whule still connected to the board
    [ble.c, ble.h, power.c]
2026-09-15 add support for smart reverse and some bug fixing
    [ble.c, ble.h, throttle.c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]
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2026-10-05 add ride profiles, speed limit and shutdown arc (v3.0.4)
    Ride settings
    - New CMD_SET_RIDE_SETTINGS (profile + speed limit mode), persisted in NVS
    and applied live without a reboot.
    - Ride profiles (Beginner/Eco/Medium/Rocket): the remote eases the throttle
    up from neutral with an ease-in ramp (braking, release and neutral pass
    through instantly); the receiver caps drive current by profile.
    - Speed limit modes (off, 20/25 km/h, 20/25 mph) are enforced by the
    receiver. Both settings are sent over BLE on every (re)connect and on
    change via new commands 0x06 and 0x09.
    USB config
    - New CMD_GET_ALL / RSP_ALL: one tagged TLV snapshot of all settings,
    read from NVS, so the config tool n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
    [ble.c, ble.h, power.c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]
2026-10-05 port to lvgl 9.1.0 for esp32s3 SIMD, dual pro colors and home animations
    - LVGL 9.1.0 + esp_lvgl_port 2.4.4 for the S3 SIMD fill/blend routines;
    vendored components updated
    - lcd.c on the LVGL 9 display API: async DMA flush, RGB565 swap in flush,
    tick callback, LVGL task on core 1 sleeping until its next timer
    - perf defaults: -O2, 240 MHz, 64/32 KB caches, 80 MHz PSRAM, 1 kHz ticks,
    15 ms refresh; LVGL pool (128 KB) malloc'd into PSRAM, BT allocs PSRAM first
    - 3 MB app partition
    - images converted to LVGL 9 ARGB8888; fonts repacked to 4 bpp (LVGL 9.1
    renders 8 bpp glyphs scrambled); unused ui_image_reference.c removed
    - dual pro palette on home/charging/low battery screens, "odo km/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
    [partitions.csv]
2026-10-05 smooth arc fills: tenth-percent arc resolution
    Gauge arcs (charging, home remote/board) and the shutdown fill ran in whole
    percents, 2.6 degree jumps that the slow tail of the ease showed as steps.
    They now run 0-1000, LVGL's 1 degree limit, so fills glide to the end.
    Callers still pass percent to the gauges; the shutdown fill takes
    SHUTDOWN_PROGRESS_MAX (1000).
2026-10-24 raise assist strength cap to 80% (v3.0.5)
    Assistive push strength now goes up to 80% of the VESC current limit (was 50%).
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2026-10-30 githooks: quote the macOS sed suffix, skip partially staged files
    `sed -i ''` expanded unquoted left file'' backups behind on macOS (hence
    the *'' ignore rules, now gone). Re-adding a formatted file also staged
    its unstaged hunks; such files are skipped now. post-commit called a
    script that no longer exists.
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2026-10-30 usb_serial: block on driver reads, drop stalled frames
    The task read one byte through stdin and slept 20 ms after every byte,
    capping RX near 50 B/s (120-200 ms per command). Read up to 64 bytes per
    usb_serial_jtag_read_bytes() call with a 10 ms timeout and parse them all;
    a frame that stalls for 50 ms mid-way resets the parser.
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2026-10-30 settings: one RAM-cached store owns all NVS; atomic calibration
    vesc_config.c becomes settings.c and owns every persisted value (prefs,
    backlight, haptics, aux, trim, snake score, throttle calibration). It
    loads once at boot from the existing namespaces and keys, so nothing is
    migrated; getters copy from RAM, setters validate, write only changed
    keys and bump settings_epoch(). No other module calls nvs_*.
    - No NVS reads in steady state: the speed/battery tasks reloaded from
    flash every ~2.5 s and the USB stream on every tick.
    - An NVS error no longer aborts (ESP_ERROR_CHECK in a UI task, and
    nvs_flash_init at boot); the remote runs on defaults instead.
    - One defaults table (10 poles, 1: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
2026-10-30 viber: one preemptible request slot, callers never block
    A request is now xQueueOverwrite()n into a 1-slot queue; the task blocks
    on it and waits each step on the same queue, so a new pattern cuts the
    current one short instead of being dropped, and durations/count can no
    longer disagree mid-update. Callers (including an LVGL animation
    callback and the button task) no longer sleep 10 ms. The startup song
    goes through the same task, haptic steps restore their frequency after
    it, LEDC setup is shared, and init returns errors instead of aborting.
2026-10-30 concurrency: atomics for cross-task flags, check task creation
    - ble_is_connected() read the flag whether or not its 10 ms mutex take
    succeeded; it is an atomic now and the mutex is gone.
    - power_check_inactivity()/power_check_charging_screen_usb() looked at
    the active screen from the main loop without the LVGL mutex.
    - ui_set_dual_home_screen() rebound widgets unlocked after 5 failed
    takes; it waits now (callers are init and the USB task).
    - volatile flags shared between tasks are stdatomic.
    - Every xTaskCreate is checked and fails init loudly.
    - button: ISR service install/handler add are checked; the isr_triggered
    flag duplicated the task notification.
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2026-10-30 logging: per-event/per-packet at DEBUG, repeated warnings once a second
    The console shares the USB-Serial-JTAG port with the config tool's binary
    protocol. Every GATTC event, notify and write completion logged at INFO;
    those are DEBUG now (compiled out at the INFO default, made explicit in
    sdkconfig.defaults). The failed-throttle-write and ADC fault warnings,
    which can fire every 20 ms, are rate-limited to once a second.
2026-10-30 battery: eFuse-calibrated ADC voltage, no fudge factor
    The reading was raw / 4095 * 3.3 V * 2 * 1.075 with the calibration
    headers included but unused. It now goes through the curve-fitting
    calibration scheme (true millivolts); the 1.075 fudge only applies on a
    chip without calibration eFuses. BATTERY_VOLTAGE_SCALE stays as a trim
    knob for divider tolerance.
    Needs hardware check: compare against a multimeter across the range and
    re-check the 2.95 V cut-off (BATTERY_LOW_VOLTAGE_THRESHOLD).
2026-10-30 power: dynamic frequency scaling, 240 MHz only while LVGL renders
    CONFIG_PM_ENABLE + tickless idle, esp_pm_configure(240/80 MHz). Without a
    lock DFS would run LVGL at 80 MHz, so the LVGL task holds a CPU_FREQ_MAX
    lock around lv_timer_handler(); between frames the CPU drops to 80. SPI
    and BT drivers take their own APB locks. No automatic light sleep.
    Needs hardware check: battery current before/after, UI frame rate, BLE
    link stability. Existing build_<variant>/ trees keep their old sdkconfig;
    delete sdkconfig.<variant> to pick up the new defaults.
2026-10-30 ble: bonded receivers only, pairing window, encrypted-only sends
    - The passkey is CONFIG_GB_BLE_PASSKEY (Kconfig, default unchanged so
    existing pairs keep working) and is no longer logged anywhere.
    - Outside a pairing window the remote only connects to receivers in its
    bond list. With no bond it is always pairing (first setup works as
    before); enabling dual connection or the new USB CMD_START_PAIRING
    (0x30) opens a 60 s window; CMD_FORGET_RECEIVERS (0x31) deletes every
    bond and drops the links.
    - Throttle frames and commands go only to links whose SMP finished. The
    receiver drops writes until then, so the settings sent at discovery
    (smart reverse, no-reverse, assist, speed limi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
2026-10-30 battery publishes state; power owns the low-battery power-off
    battery.c drove the low battery screen, the backlight and the power hold
    from its monitor task. It now only reports battery_is_low_voltage()
    (throttle cut) and battery_is_critical() (3 consecutive low readings,
    which also counts as low). power_check_battery() in the main loop does the
    alert, the warning screen and the power-off; it is not reached on the
    charging screen, where USB is supplying the remote anyway.
    The BLE shutdown command is still not sent on this path, so the
    receiver's link-loss failsafe brakes the board.
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2026-10-30 headers export only their API
    button.h exported generic TASK_STACK_SIZE/TASK_PRIORITY/MAX_CALLBACKS/
    DEBOUNCE_TIME_MS/WDT_RESET_INTERVAL_MS; they are private to button.c.
    usb_serial.h loses dead macros (USB_CDC_ENABLED/USE_*, PACKET_MIN_SIZE,
    a wrong PACKET_HEADER_SIZE); the parser state, packet struct, CRC
    (calculate_crc16 -> static usb_serial_crc16) and packet dispatcher are
    private to usb_serial.c. throttle.h's guard and NVS key exports were
    fixed with the settings move.
2026-10-30 docs: README fixes, USB protocol spec, contributing/security/changelog
    README: LVGL 9.1.0 and ESP-IDF 5.5.x, cd firmware + per-variant build
    dirs, backlight 0-100%, JBD (Jiabaida), a safety note, the pairing flow,
    hardware pointers, how to report security issues. The USB protocol doc
    it linked to now exists (firmware/docs/USB_SERIAL_PROTOCOL.md). Adds
    CONTRIBUTING.md, SECURITY.md, CHANGELOG.md and issue/PR templates.
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2026-11-04 power: tell the receiver about every power-off below 6 km/h
    The shutdown command lets the receiver skip its failsafe brake ramp on
    the disconnect that follows. It is now sent on every power-off path:
    long press (also when USB takes the remote to the charging screen),
    inactivity and critical battery, and the remote waits 500 ms for it to
    leave before suspending BLE or cutting power (only if it was sent).
    At 6 km/h or more nothing is sent, so the receiver treats the power-off
    as a lost link and brakes; below that the board is being walked or
    dragged by hand. The speed uses the motor config (poles, ratio, wheel),
    so a wrong config shifts the threshold. SHUTDOWN_MAX_KMH in ble.c.
    Needs hardwar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
